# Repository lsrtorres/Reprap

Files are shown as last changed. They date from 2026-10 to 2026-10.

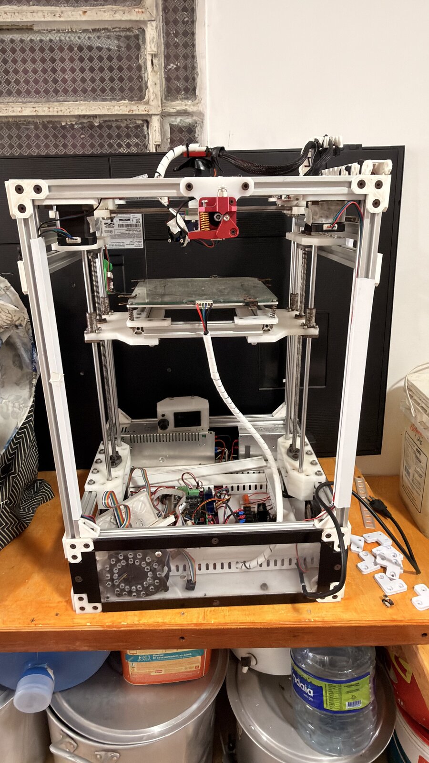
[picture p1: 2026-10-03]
Fotos/jpg/IMG_0317.jpg

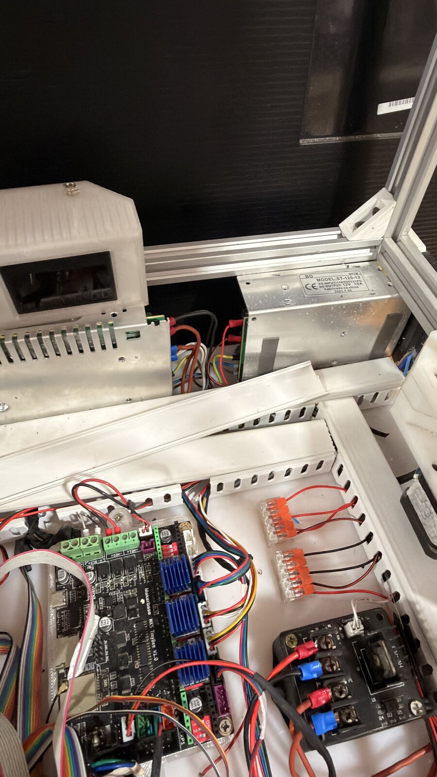
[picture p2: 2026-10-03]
Fotos/jpg/IMG_0322.jpg

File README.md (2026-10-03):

# Projeto RepRap — Redesenho para 200×200×200

Projeto colaborativo de atualização/redesenho de uma impressora 3D RepRap existente (estilo Ultimaker, gantry de eixos cruzados) para um volume de impressão de **200×200×200 mm**, reaproveitando **todos os componentes atuais** (motores, fusos, guias, eletrônica, fontes, mesa, etc.).

## Objetivos

1. Volume de impressão final: **200 × 200 × 200 mm**
2. Reaproveitar todos os componentes existentes (ver [inventário](Docs/01-inventario-componentes.md))
3. Modelagem completa em **Fusion 360**, com exportação de STEP/F3D versionados neste repositório
4. Estrutura em perfil de alumínio (temos perfis de 380 mm e 630 mm; podemos comprar mais)

## Estrutura do repositório

| Pasta | Conteúdo |
|---|---|
| `Docs/` | Documentação: inventário, análise da máquina atual, requisitos e registro de decisões |
| `Fotos/` | Fotos da impressora atual (originais `.heic` + convertidas em `Fotos/jpg/`) |
| `CAD/` | Modelos do Fusion 360 exportados (`.f3d`, `.step`) e STEPs de componentes de terceiros |
| `Firmware/` | Configuração de firmware (Marlin para MKS TinyBee) quando chegarmos nessa fase |
| `Memoria/` | Memória persistente do assistente (Claude Code) — versionada junto com o projeto |

### Memória do assistente (`Memoria/`)

O Claude Code guarda a memória por projeto em `~\.claude\projects\c--Reprap\memory\`. Para que ela seja versionada (requisito do projeto), esse diretório é uma **junction do NTFS** apontando para `Memoria/` dentro do repositório. Em uma máquina nova, após clonar o repo, recriar a junction (PowerShell):

```powershell
Remove-Item "$env:USERPROFILE\.claude\projects\c--Reprap\memory" -Recurse -Force -ErrorAction SilentlyContinue
New-Item -ItemType Junction -Path "$env:USERPROFILE\.claude\projects\c--Reprap\memory" -Target "C:\Reprap\Memoria"
```

(ajustar o sufixo `c--Reprap` conforme o caminho local do clone.)

## Documentos principais

- [01 — Inventário de componentes](Docs/01-inventario-componentes.md)
- [02 — Análise da máquina atual](Docs/02-analise-maquina-atual.md)
- [03 — Requisitos e registro de decisões](Docs/03-requisitos-e-decisoes.md)
- [04 — Conceito do novo gantry (CoreXY)](Docs/04-conceito-novo-gantry.md)
- [05 — Lista de compras](Docs/05-lista-de-compras.md)
- [06 — Conceito do eixo Z (estilo Voron Trident)](Docs/06-conceito-z-voron.md)
- [07 — Esqueleto dimensional do gantry](Docs/07-esqueleto-gantry.md)
- [08 — Esqueleto dimensional da máquina completa](Docs/08-esqueleto-maquina.md)
- [09 — Montagem peça a peça no Fusion 360 (juntas + simulação)](Docs/09-montagem-fusion.md)
- [10 — Roteiro Fusion, Fase 1: o frame](Docs/10-roteiro-fusion-fase1-frame.md)

## Fluxo de trabalho de CAD

O Fusion 360 salva os projetos na nuvem da Autodesk. Para manter o repositório como fonte de verdade colaborativa:

1. Modelar no Fusion 360 normalmente;
2. Ao fechar uma etapa, exportar `.f3d` (com histórico paramétrico) e `.step` (neutro) para `CAD/`;
3. Commitar com mensagem descrevendo a mudança;
4. STEPs de componentes comprados (motores NEMA17, perfis, trilhos MGN, etc.) ficam em `CAD/componentes/`.

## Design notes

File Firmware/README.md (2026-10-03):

# Firmware — Klipper

Decisão de 2026-10-03 ([registro](../Docs/03-requisitos-e-decisoes.md)): a impressora roda **Klipper** na **MKS SKIPR** — host (SoC quad-core, imagem da MKS com Klipper/Moonraker/Fluidd-Mainsail) e MCU (STM32) na mesma placa. O Leandro já opera outra RepRap com Klipper.

Esta pasta vai receber o **`printer.cfg`** (versionado — toda mudança de configuração entra por commit) e macros.

## Sementes do printer.cfg (valores já decididos)

| Parâmetro | Valor | Origem |
|---|---|---|
| `kinematics` | `corexy` | [Docs/04](../Docs/04-conceito-novo-gantry.md) |
| `rotation_distance` X/Y | **40** (GT2 2 mm × polia 20T) | polias existentes |
| `rotation_distance` Z (×3) | **8** (TR8×8) | [Docs/06](../Docs/06-conceito-z-voron.md) |
| Steppers | `stepper_x`, `stepper_y`, `stepper_z`, `stepper_z1`, `stepper_z2`, `extruder` | SKIPR: 6 de 7 slots |
| `[probe]`/`[bltouch]` | BLTouch | lista de compras item 11 |
| `[z_tilt]` | 3 pontos (2 frontais + 1 central traseiro) — coordenadas sairão do CAD | [Docs/06](../Docs/06-conceito-z-voron.md) |
| `[bed_mesh]` | janela 200×200 centrada em (0, −35) do sistema do anel — mapear p/ coords da mesa | [Docs/07](../Docs/07-esqueleto-gantry.md) |
| Drivers | 6× **TMC2209 em UART** (`[tmc2209 stepper_*]`, `run_current` a definir pela etiqueta dos motores); sensorless homing = opção futura | inventário (5 existentes + 1 a comprar) |
| Mesa | MK3 12 V via MOSFET externo, termistor 100k | inventário |
| Hotend | V6 Volcano 12 V, 40 W | lista de compras item 16 |
| Extrusora | direct-drive vermelha atual — `rotation_distance` a calibrar | inventário (modelo pendente) |

## Pendências

1. ~~Escolha do host~~ ✅ embutido na SKIPR
2. Gravar a imagem oficial da MKS p/ SKIPR no microSD; definir rede (Ethernet ou dongle WiFi USB)
3. Modelo dos drivers atuais (corrente de referência / jumpers de microstep na SKIPR)
4. Posições exatas dos 3 fusos para o `[z_tilt]` (sai do CAD do Z)
5. ADXL345 (opcional) para input shaper

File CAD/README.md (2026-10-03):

# CAD

Modelos do projeto.

- Raiz: montagens e peças (`.f3d` com histórico paramétrico do Fusion 360 + `.step` neutro)
- `componentes/`: STEPs de componentes comprados/padrão (gerados por script — envelopes dimensionais)
- `scripts/`: scripts Python/CadQuery que **geram** o esqueleto e os componentes — ver [Docs/07](../Docs/07-esqueleto-gantry.md) para o sistema de coordenadas e instruções de regeneração

Convenção de nomes: `NN-nome-da-peca_vX.step` (ex.: `10-esqueleto-gantry_v1.step`). O `.f3d` correspondente acompanha a mesma numeração.

Regra de ouro: dimensões "mestras" vivem em [`scripts/parametros.py`](scripts/parametros.py) e no registro de decisões — se mudar uma dimensão de conceito, mudar lá e regenerar.

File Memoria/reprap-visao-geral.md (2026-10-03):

---
name: reprap-visao-geral
description: "Projeto RepRap 200x200x200 - repo, convencoes e onde esta a memoria real do projeto"
metadata:
  node_type: memory
  type: project
  originSessionId: 7e4093a0-5cda-47a9-a74d-79533ce589c3
  modified: 2026-10-03T14:39:08.445Z
---

Redesenho de impressora RepRap (estilo Ultimaker: XY cruzado no topo, mesa desce no Z) para volume 200×200×200 mm, reaproveitando todos os componentes. Repo local `C:\Reprap` → `https://github.com/lsrtorres/Reprap.git` (branch main, identidade git local: lsrtorres / lsrtorred@gmail.com).

**A memória real do projeto vive no repositório** (requisito do Leandro: tudo commitável): `Docs/01-inventario-componentes.md` (inventário + medições pendentes), `Docs/02-analise-maquina-atual.md`, `Docs/03-requisitos-e-decisoes.md` (registro de decisões), `Docs/04-conceito-novo-gantry.md`. Decidido em 2026-10-03: **CoreXY aprovado** (anel 440 mm; guias Y = MGN9×300 nos laterais; viga X = perfil 20×20 + MGN9 na face frontal; juntas XY estilo Voron com polias encapsuladas; correias ancoram por ranhuras atrás do toolhead). **Z estilo Voron Trident**: 3 guias MGN (2 frontais + 1 central traseira); acionamento proposto = 2 TR8 frontais + seguidor (TinyBee só tem 5 slots de driver — detalhes em `Docs/06`). Z confirmado: **Trident completo** — nova placa **MKS SKIPR** (Klipper host embutido + MCU STM32, 7 slots; TinyBee vira reserva; exceção ao reuso aprovada), 3× fuso TR8×8×400 + castanhas bronze com 3 motores independentes, mancais KP08/KFL08, motores embaixo, BLTouch; +1 NEMA17 e +1 driver a comprar; hotend novo V6 Volcano 12 V (extrusora vermelha continua). **Firmware: Klipper** (Leandro já tem outra RepRap com Klipper; `z_tilt` 3 pontos; display MKS TFT vira reserva; UI Mainsail/Fluidd). Sementes do printer.cfg em `Firmware/README.md`. Esqueleto CAD paramétrico em `CAD/scripts/` (CadQuery; venv em `C:\Reprap\.venv`, Python 3.12): `esqueleto_gantry.py` → `CAD/10-...step` e `esqueleto_maquina.py` → `CAD/11-esqueleto-maquina_v1.step` (máquina completa com Z Trident; verificações automáticas de curso XY/Z; drivers = TMC2209). Coordenadas/stack-up em `Docs/07` e `Docs/08`. Perfis (correção final): comprar 3×440 + 11×400; colunas = 4×630 do estoque inteiras (só existem 4) + coluna Z traseira é um 440 comprado; único corte do projeto: viga X 400→340. Fluxo Fusion (Docs/09): upload de cada STEP no Data Panel → componente X-ref inserido um a um → juntas rígidas + sliders + motion link (fuso 8mm/volta) p/ simular movimentos; Leandro traz STEPs de fabricante (MGN9C, KP08, castanha T8); mudou conceito → editar `parametros.py`, regenerar, re-upload como nova versão do mesmo item. Barras Ø8 eram guias do Z atual; serão aposentadas. Sempre ler esses docs no início da sessão e registrar decisões novas lá, com commit.

**Status em 2026-10-03**: Leandro montando a **Fase 1 (frame, 17 perfis)** no Fusion seguindo `Docs/10` (método: gabarito 11-esqueleto aterrado + Move "Point to Point" por vértice; Fusion não tem tipo "montagem" — é Design comum com componentes X-ref). Ele já baixou o carrinho HIWIN **MGN9H** (`CAD/componentes/mgn9h-carrinho-hiwin.step`) — ⚠️ confirmar se os carrinhos físicos são MGN9**C** (38,5 mm, assumido no esqueleto) ou MGN9**H** (~48,9 mm — cursos ainda fecham, mas `parametros.py` precisaria de MGN9_BLOCO_L atualizado e regenerar). Próximo: Fase 2 = trilhos + gantry + sliders.

CAD: Fusion 360 (nuvem Autodesk); exportar .f3d + .step para `CAD/`. Fotos HEIC convertidas para JPG em `Fotos/jpg/` (ImageMagick instalado via winget; HEIC não é legível diretamente). [[leandro-perfil]]

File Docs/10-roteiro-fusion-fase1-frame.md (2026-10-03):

# 10 — Roteiro Fusion, Fase 1: o frame (16 perfis)

Companheiro do [09](09-montagem-fusion.md). Método: usar o **esqueleto como gabarito** e encaixar cada componente nele com *Point to Point* — zero digitação de coordenada, precisão total.

## Fase 0 — Projeto e uploads

1. Data Panel → **New Project**: `Reprap`; dentro dele, pasta `componentes`
2. Upload para `componentes/`: `perfil-2020-630.step`, `perfil-2020-440.step`, `perfil-2020-400.step` (os 3 bastam p/ a Fase 1)
3. Upload na raiz do projeto: `11-esqueleto-maquina_v1.step` (o gabarito)
4. Aguardar o processamento de cada upload terminar (ícone pára de girar)

## Fase 1 — Montagem do frame

### Preparação

1. **New Design**, salvar como `montagem-reprap` (unidades: mm — padrão)
2. Inserir o gabarito: botão direito em `11-esqueleto-maquina_v1` → *Insert into Current Design* → **OK sem mover nada**
3. Botão direito no gabarito na árvore → **Ground**. Renomear para `GABARITO`

### Encaixe de cada perfil (receita de 2 passos)

Para cada linha da tabela abaixo:

1. *Insert into Current Design* no perfil indicado → OK (ele cai na origem)
2. **Se a tabela pedir rotação**: `M` (Move/Copy) → *Components* → girar **90° no eixo indicado** (o pivô não importa — o passo 3 corrige a posição)
3. `M` → *Move Type: **Point to Point*** → clicar num **vértice de canto** do perfil inserido → clicar no **vértice correspondente** do membro homônimo do GABARITO. Pronto: encaixado com exatidão
4. Renomear a instância na árvore com o nome da tabela

| Ordem | Componente | Instância (nome) | Rotação | Onde encaixa (membro do gabarito) |
|---|---|---|---|---|
| 1–4 | `perfil-2020-630` | `coluna-0..3` | nenhuma (já é vertical) | 4 colunas dos cantos |
| 5–6 | `perfil-2020-400` | `base-lateral-esq/dir` | **90° em X** | anel da base, laterais |
| 7–8 | `perfil-2020-400` | `base-frente/tras` | **90° em Y** | anel da base, frente e trás |
| 9–10 | `perfil-2020-400` | `deck-lateral-esq/dir` | **90° em X** | deck, laterais |
| 11–12 | `perfil-2020-400` | `deck-frente/tras` | **90° em Y** | deck, frente e trás |
| 13–14 | `perfil-2020-440` | `perfil-esq/dir` | **90° em X** | anel superior, laterais (sobre as colunas) |
| 15–16 | `perfil-2020-400` | `perfil-frente/tras` | **90° em Y** | anel superior, frente e trás |
| 17 | `perfil-2020-440` | `coluna-z-tras` | nenhuma | coluna central traseira (do deck ao anel) |

> Regra de bolso da rotação: membro que corre na direção **Y** (laterais) → girar em **X**; membro que corre em **X** (frente/trás) → girar em **Y**. O perfil é simétrico, o sinal do giro não importa.

### Espans de referência (conferência, se quiser medir)

| Grupo | Ocupação |
|---|---|
| Colunas | (x, y) = (±210 ± 10), z −650 … −20 |
| Anel base | z −650 … −630 |
| Deck | z −480 … −460 |
| Anel superior | z −20 … 0 (laterais de 440 cobrem y −220 … +220) |
| Coluna Z traseira | (0 ± 10, 210 ± 10), z −460 … −20 |

### Fechamento da fase

1. Selecionar os 17 componentes (não o GABARITO) → botão direito → **Rigid Group** → nomear `frame`
2. **Ground** num deles (o grupo todo trava)
3. Ocultar o `GABARITO` (olhinho na árvore) — **não apagar**: ele guia as fases 2 (trilhos + gantry) e 3 (Z + mesa)
4. Conferir com *Inspect → Measure*: externo 440 × 440, altura total 650 do piso ao topo do anel

### Resultado esperado

Frame completo: 4 colunas + 3 anéis (base, deck, superior) + coluna Z traseira — idêntico ao gabarito, mas com cada perfil sendo um componente X-ref independente, pronto para receber trilhos e juntas na Fase 2.

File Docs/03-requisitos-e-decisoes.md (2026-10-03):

# 03 — Requisitos e registro de decisões

Este documento é a memória viva do projeto. Toda decisão relevante entra na tabela de decisões com data e justificativa. Alterações via commit — o histórico do git é o registro oficial.

## Requisitos

| # | Requisito | Tipo |
|---|---|---|
| R1 | Volume de impressão de 200 × 200 × 200 mm | Obrigatório |
| R2 | Reaproveitar todos os componentes atuais (motores, fusos, guias, eletrônica, fontes, mesa, display, extrusora/hotend) | Obrigatório |
| R3 | Estrutura em perfil de alumínio; estoque atual: 380 mm e 630 mm; compra de perfis adicionais é permitida | Obrigatório |
| R4 | Fixação dos perfis com cantoneiras externas, parafuso M5 + porca T (padrão atual) — pode evoluir se justificado | Desejável |
| R5 | Modelagem completa em Fusion 360, com F3D/STEP versionados no repositório | Obrigatório |
| R6 | Projeto colaborativo: tudo (docs, CAD, decisões, memória) versionado no git | Obrigatório |
| R7 | Peças impressas em 3D fabricáveis na própria máquina atual (bootstrap) | Desejável |
| R8 | Novo roteamento de correias: chegada limpa e direta das correias ao toolhead e ao gantry XY (insatisfação com o esquema atual estilo Ultimaker) | Obrigatório |

## Registro de decisões

| Data | Decisão | Justificativa | Status |
|---|---|---|---|
| 2026-10-03 | Repositório git como fonte de verdade do projeto (docs + CAD exportado + fotos) | Projeto colaborativo; Fusion 360 fica na nuvem Autodesk, mas exportações F3D/STEP são versionadas | ✅ Ativa |
| 2026-10-03 | Fotos originais `.heic` mantidas + conversões `.jpg` (1600 px) para visualização no GitHub | GitHub não renderiza HEIC; JPGs facilitam a colaboração | ✅ Ativa |
| 2026-10-03 | Perfis adicionais podem ser comprados (20×20, mesmo padrão) | Necessário: quadro atual (380 mm) só entrega ~180 mm de curso | ✅ Ativa |
| 2026-10-03 | Fusos Z: **manter os TR8 atuais** | Confirmado que já são trapezoidais TR8 — sem motivo para troca | ✅ Ativa |
| 2026-10-03 | **Cinemática do novo gantry: CoreXY** — correias ancoram direto no carro do toolhead, motores fixos no quadro — ver [04-conceito-novo-gantry.md](04-conceito-novo-gantry.md) | Atende R8; elimina eixos rotativos e correias perimetrais do estilo Ultimaker; reusa os 2 motores XY e polias; Marlin `COREXY` nativo na TinyBee. **Aprovado pelo Leandro** | ✅ Ativa |
| 2026-10-03 | **Viga X = perfil 20×20 + trilho MGN montado nele**; toolhead corre no MGN | Pedido do Leandro (robustez); perfil dá rigidez torcional que barras não dão | ✅ Ativa |
| 2026-10-03 | Trilho MGN na **face frontal** da viga X (não no topo), estilo Voron | Sugestão do Leandro: placa do toolhead plana, CG do cabeçote perto do trilho (menos momento), topo livre p/ esteira — detalhes em [04](04-conceito-novo-gantry.md) | ✅ Ativa |
| 2026-10-03 | ~~Guias Y = 2 barras Ø8×400 com LM8UU~~ | Substituída no mesmo dia ao confirmar que existem 4 trilhos MGN9 | ♻️ Substituída |
| 2026-10-03 | **Guias Y = 2× trilho MGN9 300 mm** parafusados nos perfis laterais; viga X usa o 3º trilho; 4º fica de reserva | **Mantém a solução da máquina atual** (o Y já corre em 1 MGN9 de cada lado; barras lisas só existem no Z); carros Y viram placas simples e dispensa LM8UU | ✅ Ativa |
| 2026-10-03 | **Juntas XY estilo Voron**: polias desviadoras **encapsuladas** dentro das peças que unem a viga X aos carrinhos Y (não expostas no topo) | Pedido do Leandro; protege as polias, alinha os dois planos de correia por construção e enrijece a junta | ✅ Ativa |
| 2026-10-03 | **Ancoragem das correias por ranhuras** na traseira do carro do toolhead (dente da GT2 morde a ranhura impressa), uma por plano de correia | Pedido do Leandro; elimina a peça única "de dois andares", facilita troca de correia e tensionamento | ✅ Ativa |
| 2026-10-03 | **Z estilo Voron Trident nas guias**: 3 guias MGN verticais (2 colunas frontais + 1 central traseira), mesa em 3 pontos; torres atuais com barras Ø8 aposentadas | Pedido do Leandro; conceito detalhado em [06-conceito-z-voron.md](06-conceito-z-voron.md) | ✅ Ativa |
| 2026-10-03 | ~~Acionamento do Z (Opção A): 2 fusos frontais + seguidor passivo~~ | Substituída no mesmo dia: Leandro decidiu comprar placa com mais slots para viabilizar o Trident completo | ♻️ Substituída |
| 2026-10-03 | ~~Nova placa: MKS Monster8 V2~~ | Substituída no mesmo dia: com o firmware fechado em Klipper, o Leandro escolheu a placa com host embutido | ♻️ Substituída |
| 2026-10-03 | **Nova placa: MKS SKIPR** (SoC quad-core com Klipper host embutido + MCU STM32, **7 slots de driver**, entrada 12–24 V); TinyBee vira reserva. **Exceção aprovada ao R2** (reuso total) | Decisão do Leandro; elimina host externo (sem Pi, sem buck 5 V), reusa os 5 drivers atuais; 6 slots usados (X, Y, 3×Z, E) + 1 folga; rede via Ethernet ou dongle WiFi USB | ✅ Ativa |
| 2026-10-03 | **Acionamento do Z: Trident completo — 3 fusos TR8×8×400 com 3 motores independentes** (`G34`/`Z_STEPPER_AUTO_ALIGN` de 3 pontos com BLTouch) | Com a Monster8 há slots de sobra; auto-tram verdadeiro (rolagem + inclinação); requer +1 NEMA17, +1 fuso/castanha/mancal/acoplador e +1 driver | ✅ Ativa |
| 2026-10-03 | **Fusos Z novos: 3× TR8×8 (passo 8) × 400 mm + castanhas de bronze**; apoio em **mancal KP08/KFL08** na base, motor embaixo; TR8 atuais viram reserva | Especificação do Leandro (qtde atualizada de 2→3 com o Trident completo); passo 8 dá Z rápido (400 steps/mm @ 16 µsteps) | ✅ Ativa |
| 2026-10-03 | **Firmware: Klipper** (TinyBee/ESP32 nem roda Klipper). Nivelamento: `Z_TILT_ADJUST` 3 pontos + `BED_MESH_CALIBRATE` com BLTouch. Display MKS TFT atual → reserva (UI = Mainsail/Fluidd no navegador) | Decisão do Leandro — já opera outra RepRap com Klipper; CoreXY + input shaper é o ponto forte do Klipper | ✅ Ativa |
| 2026-10-03 | **Host do Klipper: embutido na MKS SKIPR** | Decisão do Leandro — resolve a decisão aberta de host junto com a placa | ✅ Ativa |
| 2026-10-03 | **Sonda BLTouch** no toolhead | Especificação do Leandro; vidro exige sonda de pino; TinyBee tem porta 3D-Touch; habilita `G34` + `G29` | ✅ Ativa |
| 2026-10-03 | **Hotend novo: V6 com bloco Volcano, 12 V** (cartucho 40 W + termistor) | Especificação do Leandro; substitui o hotend atual; extrusora vermelha direct-drive continua | ✅ Ativa |
| 2026-10-03 | Divisão de energia: fonte **360 W → mesa + hotend + motores/placa**; fonte **120 W → ventoinhas/iluminação/aux** (detalhar na fase de eletrônica) | Mesa MK3 12 V puxa ~10–11 A sozinha; 30 A comportam o sistema todo com margem | ✅ Ativa |
| 2026-10-03 | Anel XY com perfis 20×20 de **440 mm** (vão interno 400 mm) — **aprovado para compra** | Comporta 200 mm de curso com folga nos dois eixos; dimensional em [04](04-conceito-novo-gantry.md); lista de compras em [05](05-lista-de-compras.md). **OK do Leandro** | ✅ Ativa |

## Próximos passos

1. **[Leandro]** Fazer o pedido da [lista de compras](05-lista-de-compras.md) (perfis: **3× 440 + 11× 400** — estoque de 630 confirmado em 4, usados inteiros)
2. **[Leandro]** Montagem no Fusion pelo fluxo do [09](09-montagem-fusion.md): upload dos STEPs de `CAD/componentes/` + STEPs de fabricante (MGN9C, KP08, castanha T8), inserção um a um, juntas rígidas/sliders e simulação de movimentos
3. Modelagem das peças impressas no Fusion 360, na ordem do [08](08-esqueleto-maquina.md): juntas XY, carro do toolhead (Volcano+BLTouch), blocos de motor, braços da mesa, suportes do deck/baia
4. **[Leandro]** Pendências leves do inventário: etiqueta dos motores, modelo da extrusora, contagem dos perfis 380

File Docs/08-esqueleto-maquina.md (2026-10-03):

# 08 — Esqueleto dimensional da máquina completa

Gerado por [`CAD/scripts/esqueleto_maquina.py`](../CAD/scripts/esqueleto_maquina.py), que importa o gantry do script anterior e adiciona o frame vertical e o Z Trident. Saída: **`CAD/11-esqueleto-maquina_v1.step`** (abre direto no Fusion 360). Mesmo sistema de coordenadas do [Docs/07](07-esqueleto-gantry.md) (origem no centro do anel superior, z=0 no topo do anel).

## Arquitetura vertical (de cima para baixo)

| z (mm) | Elemento |
|---|---|
| −20 … 0 | **Anel superior** (2× 440 laterais sobre as colunas + 2× 400 frente/trás) + gantry CoreXY |
| −55 | Ponta do bico (V6 Volcano, estimado) = topo do vidro com a mesa em **home** |
| −50 … −350 | **Trilhos Z** MGN9×300: 2 nas colunas frontais (face interna) + 1 na coluna central traseira |
| −67 … −267 | Topo dos braços da mesa ao longo do curso de **200 mm** |
| −55 … −455 | **Fusos TR8×8 × 400** (3×): sobra +12 mm acima da castanha em home, +168 mm na base |
| −460 … −480 | **Deck** (4× perfil 400 entre colunas): mancais KP08/KFL08 em cima, motores Z pendurados embaixo |
| −480 … −630 | **Baia da eletrônica**: 150 mm internos p/ SKIPR, 2 fontes, MOSFET, WAGOs |
| −630 … −650 | **Anel da base** (4× perfil 400 entre colunas), no chão |
| −650 | Piso |

- **Colunas**: 4× perfil **630 inteiro** nos cantos (do piso até sob o anel superior — estoque confirmado: exatamente 4) + 1 coluna central traseira de **440** (comprada — mesma medida das laterais do anel), do deck ao anel — carrega o 3º trilho Z
- **Mesa**: rígida em 3 pontos (**sem molas** — `z_tilt` + `bed_mesh` substituem o nivelamento manual); vidro 3 + MK3 3 + espaçador 6 + braço 8
- Posições dos fusos: frontais (±180, −195), traseiro (0, +195) — coordenadas que depois alimentam o `[z_tilt]` do Klipper

## Verificações automáticas (o script falha se alguma quebrar)

| Checagem | Resultado |
|---|---|
| Curso XY do bico ≥ 200 | 261,5 mm ✓ (folga +30,8/lado) |
| Fuso cobre a castanha em todo o curso Z | ✓ (+12 topo / +168 base) |
| Carrinho Z dentro do trilho em todo o curso | ✓ (−71…−271 dentro de −69,2…−330,8) |
| Baia ≥ 90 mm p/ fontes | ✓ 150 mm |
| Mesa não colide com colunas | ✓ |

## Lista de corte consolidada (perfis 20×20)

| Origem | Peças |
|---|---|
| **Comprar** | 3× **440** + 11× **400** |
| **Estoque (630)** | 4× inteiros (colunas dos cantos) — sem corte |
| **Estoque (380)** | livres p/ travessas da baia (suportes de fonte/SKIPR) e reforços |

> Único corte de perfil do projeto: a viga X (400 → 340).

## Fluxo com o Fusion 360

O STEP é o formato neutro que o Fusion abre nativamente — **todo o trabalho de modelagem continua no Fusion 360**; os scripts só produzem a referência dimensional:

1. *File → Open* (ou *Insert → Insert CAD*) no `11-esqueleto-maquina_v1.step` — a árvore vem com os componentes **nomeados** (perfis, trilhos, fusos, motores…)
2. `Ground` nos perfis; modelar cada peça impressa como componente novo **referenciando as faces do esqueleto**
3. O STEP não traz histórico paramétrico nem juntas (é geometria estática) — se uma dimensão de conceito mudar, eu altero [`parametros.py`](../CAD/scripts/parametros.py), regenero, e re-importamos a nova versão
4. Peças modeladas voltam ao repositório como F3D + STEP em `CAD/`

## Próximas peças a modelar (Fusion 360)

1. Juntas XY com polias encapsuladas (2×, espelhadas)
2. Carro do toolhead (ranhuras GT2 + V6 Volcano + BLTouch + extrusora vermelha)
3. Blocos dos motores A/B e das polias dianteiras
4. Braços da mesa (3×) com alojamento de castanha e interface MGN9
5. Suportes de mancal/motor Z no deck; suportes da SKIPR/fontes na baia
6. Cantoneiras/uniões dos perfis (padrão M5 + porca T)

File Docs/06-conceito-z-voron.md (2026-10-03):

# 06 — Conceito do eixo Z (estilo Voron Trident)

**Decisão do Leandro (2026-10-03):** o Z passa a ser ancorado em **guias MGN verticais — duas na frente e uma no centro traseiro** —, com a mesa suportada em 3 pontos, no estilo Voron Trident. As torres atuais (fuso + 2 barras Ø8 cada) são aposentadas; as barras Ø8×~400 viram reserva.

## Arquitetura

```
   vista de cima (anel da base)          vista frontal
   ┌─────────[MGN]─────────┐          ║ col.    col. ║
   │          trás          │          ║ MGN     MGN ║
   │                        │          ║ │         │ ║
   │      mesa 220×220      │          ║ ├─ mesa ──┤ ║
   │     (3 braços p/       │          ║ │  braços │ ║
   │      os carrinhos)     │          ║ TR8     TR8 ║
 [MGN]                   [MGN]         ║ (fusos)     ║
   └──frente────────────────┘          ╚═════════════╝
```

- **Guias**: 3× trilho MGN9×300 vertical — 2 parafusados nas faces internas das colunas frontais + 1 numa coluna central traseira (perfil 20×20 adicionado ao quadro). Curso útil ≈ 300 − carrinho (39) − margens ≈ **~250 mm** → atende os 200 mm com folga
- **Mesa**: MK3 220×220 + vidro sobre 3 braços (frente-esq., frente-dir., centro-trás) parafusados nos carrinhos — suporte em 3 pontos, o único que não empena a mesa por definição
- **Trilhos**: temos 1 MGN9×300 de reserva; **comprar 2** (já estão na [lista de compras](05-lista-de-compras.md))
- **Colunas**: perfis de 630 mm existentes; a coluna central traseira pode sair do estoque de 380 mm se a altura da zona Z permitir (fechar no CAD)

## Acionamento — Trident completo com MKS SKIPR

A TinyBee tem só 5 slots de driver (X, Y, Z, E0, E1) — com CoreXY + extrusora sobrariam 2 para o Z. **Decisão (2026-10-03): comprar uma MKS SKIPR** (SoC quad-core com **Klipper host embutido** + MCU STM32, 7 slots de driver, entrada 12–24 V) e fazer o **Trident completo**:

- **3 fusos TR8 × 400 mm, passo 8 mm** (TR8×8, 4 entradas) + **castanhas de bronze** — frontal-esq., frontal-dir. e central traseiro; os TR8 atuais viram reserva
- **3 motores NEMA17 independentes** (2 existentes + **1 a comprar**), cada um no seu slot → **`Z_TILT_ADJUST` do Klipper em 3 pontos** com a BLTouch: auto-tram verdadeiro de rolagem **e** inclinação (firmware decidido: **Klipper**)
- **Mancais KP08 ou KFL08 (Ø8)** na base, um por fuso — motor embaixo, acoplador 5×8, mancal logo acima, ponta superior do fuso livre
- **Sonda: BLTouch** — `Z_TILT_ADJUST` + `BED_MESH_CALIBRATE` sobre o vidro
- Slots da SKIPR: X, Y, E0 + 3× Z = 6 usados, 1 de folga (no Klipper cada stepper é declarado livremente no `printer.cfg`)
- **Drivers**: reaproveitam-se os 5 atuais + 1 igual a comprar (identificar o modelo — pendência do inventário); Klipper aceita qualquer driver step/dir; upgrade opcional futuro: jogo de TMC2209 (UART)
- **TinyBee**: vira reserva (exceção ao requisito R2 aprovada pelo Leandro) — ESP32 não roda Klipper de qualquer forma
- **Host Klipper**: **embutido na SKIPR** (sem Pi externo); rede via Ethernet RJ45 ou dongle WiFi USB; interface Mainsail/Fluidd no navegador

> `rotation_distance` no Klipper: Z com TR8×8 = **8**; XY com GT2 + polia 20T = **40**.

Alternativas descartadas: manter TinyBee com 2 fusos + seguidor passivo (pitch não ajustável por software); 3 fusos sincronizados por correia (tram mecânico).

## O que é liberado dos componentes atuais

| Componente | Destino |
|---|---|
| 4× barra Ø8×~400 (torres) | Reserva |
| 8× LM8UU (ou similares das torres) | Reserva |
| 2× fuso TR8 atual | Reserva (substituídos por 3× TR8×8 400 mm novos) |
| Hotend atual (envolto em fita) | Reserva (substituído por V6 Volcano 12 V) |
| **MKS TinyBee V1.0** | Reserva (substituída pela Monster8 V2 — exceção ao R2 aprovada) |
| Perfis das torres | Voltam ao estoque (380/630) |

## Pendências desta fase

1. ~~Confirmar acionamento~~ ✅ Opção A com TR8×8 400 + KP08/KFL08 + BLTouch
2. CAD: braços da mesa, suportes de fuso/motor, posição exata da coluna traseira, altura da zona Z (dimensionar com o curso de 200 + espessuras da mesa)

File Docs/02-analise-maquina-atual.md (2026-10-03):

# 02 — Análise da máquina atual

Baseada nas fotos de 2026-10-03 (`Fotos/jpg/IMG_0317...0328`). A máquina está montada e **funcional**.

## Arquitetura geral

Impressora de pórtico superior **estilo Ultimaker**:

- **XY no topo**: cabeçote na interseção de eixos cruzados, acionado por correias GT2. O gantry XY é **todo guiado por trilhos MGN9** (Y: um de cada lado; X: no eixo transversal) — barras lisas só existem no Z. Motores X/Y fixados por baixo dos perfis superiores, nos cantos traseiros (IMG_0328/0320/0326).
- **Z**: a mesa desce durante a impressão. Duas torres laterais, cada uma com 1 fuso TR8 central + 2 barras lisas Ø8×~400; os fusos são acionados por motores no **topo** das torres (IMG_0317). Porcas de bronze nas plataformas (IMG_0325).
- **Cabeçote**: extrusora direct-drive (corpo vermelho) sobre o carro central, hotend para baixo (IMG_0317/0326). Cabos levados por esteira porta-cabos impressa em branco.
- **Mesa**: vidro com clipes sobre plataforma impressa com 4 molas de nivelamento (IMG_0317/0325).
- **Base**: caixa inferior em perfis + chapas perfuradas brancas abrigando as 2 fontes, a MKS TinyBee, o MOSFET da mesa e a distribuição WAGO; 2 ventoinhas no painel frontal (IMG_0321/0322/0323).
- **Estrutura**: perfis de alumínio unidos por placas/cantoneiras impressas externas com M5 + porca T. Display no meio da coluna frontal.

## Pontos fortes (a preservar)

1. **Arquitetura estável**: cabeçote leve no XY, massa da mesa só no Z — bom para velocidade.
2. **Eletrônica moderna**: MKS TinyBee (ESP32) roda Marlin 2.x com WiFi — ótima base.
3. **Caixa de eletrônica separada** na base, com ventilação própria.
4. **Distribuição elétrica organizada** com WAGO e MOSFET externo para a mesa.
5. Estrutura em perfil de alumínio — fácil de redimensionar e expandir.

## Fragilidades observadas (candidatas a melhoria no redesenho)

1. **Peças impressas estruturais grandes** (plataformas do Z, blocos do gantry) — algumas aparentam desgaste/folga; redesenhar com reforço ou substituir por conjuntos mais rígidos.
2. **Fusos Z aparentam ser barra roscada comum** com sinais de oxidação/sujeira (IMG_0323/0324) — se confirmado, considerar limpeza/lubrificação ou upgrade para TR8 (mantendo se o objetivo for custo zero).
3. **Acionamento Z por cima** com fuso longo em balanço embaixo — alinhamento crítico; avaliar mancal inferior.
4. **Cabeamento** parcialmente solto na caixa da base — refazer com canaletas já existentes e identificação.
5. **Hotend envolto em fita** (IMG_0326) — avaliar estado térmico real, silicone sock ou reisolamento.
6. **Tensionamento de correia por esticador simples** — prever tensionadores ajustáveis no redesenho.
7. **Fonte 1 de 120 W (12 V 10 A)**: se a mesa aquecida for 12 V ~10–12 A, a soma com hotend+motores exige as duas fontes bem separadas por função — documentar a divisão atual antes de mexer.

## Implicações para o redesenho 200×200×200

- **O quadro atual não entrega 200 mm**: perfis de 380 mm (20×20) dão vão interno de ~340 mm, e o curso real medido é **~180 mm** — os blocos deslizantes e o carro central do gantry Ultimaker consomem ~160 mm de vão. Para 200 mm de curso será preciso **comprar perfis maiores para o anel XY** e/ou mudar para uma cinemática que consuma menos vão (CoreXY).
- O Leandro quer **mudar o roteamento das correias** (como chegam ao toolhead e ao próprio gantry) — ver [04-conceito-novo-gantry.md](04-conceito-novo-gantry.md).
- Curso Z de 200 mm é tranquilo com as torres atuais (perfis de 630 mm dão espaço de sobra para fuso + mesa + base).
- Mesa MK3 220×220 comporta os 200×200 úteis com margem de 10 mm por lado.
- A caixa de eletrônica na base pode ser mantida conceitualmente igual, só redimensionada.

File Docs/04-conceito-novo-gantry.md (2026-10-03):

# 04 — Conceito do novo gantry XY (roteamento de correias)

**Motivação (R8):** no gantry atual, estilo Ultimaker, as correias não chegam diretamente ao toolhead: os motores acionam eixos rotativos, que acionam 4 correias perimetrais, que movem blocos deslizantes, que movem as barras cruzadas, que finalmente movem o toolhead. São muitos elementos em série (folgas se somam), tensionamento difícil e manutenção chata. O Leandro pediu explicitamente para mudar como as correias chegam ao toolhead e ao gantry.

## Opções avaliadas

### Opção A — CoreXY (recomendada ✅)

Duas correias contínuas em dois planos empilhados (~10 mm de distância vertical). **As duas correias ancoram diretamente no carro do toolhead** — sem eixos intermediários, sem blocos acionados por correia.

```
  motor A ◼──────────────◼ motor B      (traseira)
         │╲              ╱│
         │ ╲            ╱ │
  guia Y │  ╲__________╱  │ guia Y
         │  [ toolhead ]──┼── correias ancoram aqui
         │  ╱  viga X  ╲  │
         │ ╱            ╲ │
         ○╱              ╲○             (polias frontais)
```

- ΔA = ΔX + ΔY ; ΔB = ΔX − ΔY (Marlin: `COREXY`, suportado nativamente pela MKS TinyBee)
- **Reuso**: 2× NEMA17 XY, 2 polias motoras GT2 20T, 3 dos 4 trilhos MGN9×300 (2 guias Y + 1 viga X)
- **Comprar**: ~5 m de correia GT2 6 mm, ~8 polias desviadoras (idlers lisos Ø5 mm, ou rolamentos F695 empilhados), parafusos
- Motores ficam **fixos no quadro** (cantos traseiros) → menos massa móvel que qualquer alternativa
- Tensionamento simples: parafuso tensor na ancoragem do carro (estilo Voron)

> **Status: APROVADA pelo Leandro em 2026-10-03** (registro em [03-requisitos-e-decisoes.md](03-requisitos-e-decisoes.md)).

### Opção B — Cartesiano "Prusa de teto" / Markforged (H-Bot)

H-Bot usa 1 correia só, mas aplica momento de giro na viga X — exige trilhos lineares rígidos nos dois lados, senão trava/racking. Markforged complica os desvios. Sem vantagem real sobre CoreXY aqui. ❌

### Opção C — Ultimaker melhorado

Manter cinemática e só limpar o roteamento. Não resolve a insatisfação (as correias continuam chegando indiretamente ao toolhead) e continua consumindo ~160 mm de vão. ❌

## Arquitetura das guias (decidida 2026-10-03, revisada após confirmação dos 4× MGN9)

- **Y (2×)**: **trilhos MGN9×300 parafusados no topo dos perfis laterais** do anel XY — mantém o conceito da máquina atual (o Y já corre em MGN9 dos dois lados). Os carros Y são as **juntas XY estilo Voron**: peça impressa que une o carrinho Y à viga X **com as polias desviadoras encapsuladas dentro dela**, nos dois planos de correia — nada de polia exposta no topo
- **X (viga)**: **perfil 20×20 + trilho MGN (~300 mm) montado na face frontal** (estilo Voron/RatRig) — o perfil dá rigidez à viga, o trilho guia o toolhead. Montagem frontal (e não no topo) porque: placa do toolhead fica plana e parafusa direto no carrinho (sem "L" contornando a viga), o trilho fica mais perto do centro de massa do cabeçote (menos momento nas acelerações) e o topo da viga fica livre para esteira porta-cabos e endstop. Trilho fixado com parafusos M3 + porcas T no canal do perfil
- **Ancoragem das correias no toolhead**: as pontas das correias prendem na **traseira do carro do toolhead por ranhuras GT2 impressas** (o dente da correia morde a ranhura), uma ranhura em cada plano de correia, com canal de saída para o excedente — sem peça única de dois andares. Tensionamento puxando a ponta e recravando na ranhura (estilo Voron)

```
             topo livre (esteira)
            ┌──────────┐
   carrinho │  perfil  │
   MGN  ┌─┐ │  20×20   │
  ══════│█│▌│          │
 trilho └─┘ │          │
        │   └──────────┘
  placa │
  plana ├── extrusora/hotend (CG perto do trilho)
        │
```

## Dimensional (CoreXY, curso 200×200, números reais)

Anel de **440 mm externo** (vão interno 400 mm) — aprovado para compra em 2026-10-03. Com os trilhos MGN9×300 nos perfis laterais, o curso é limitado pelos trilhos, e 440 mm dão o espaço necessário para trilho + blocos de motor/polias nos cantos.

| Elemento | Valor | Observação |
|---|---|---|
| Anel XY (externo) | **440 × 440 mm** | Perfil 20×20 a comprar |
| Vão interno | 400 × 400 mm | Blocos de motor (traseira) e polias (frente) nos cantos |
| Guias Y | 2× MGN9×300 no topo dos perfis laterais | Trilho centrado: sobra 70 mm em cada ponta p/ os blocos de canto |
| Carro Y (cada lado) | placa ~45 mm sobre o carrinho MGN9 | Leva as polias de desvio das correias |
| Viga X | perfil 20×20 × **~360–400 mm** + MGN9×300 na face frontal | Comprimento exato no CAD; pontas parafusam nos carros Y |
| Curso X | ~255 mm disponíveis | Trilho 300 − carrinho (~29) − placa do toolhead; **precisa de 200** ✓ folga ~55 |
| Curso Y | ~250 mm disponíveis | Trilho 300 − placa do carro Y (~45); **precisa de 200** ✓ folga ~50 |
| Mesa 220×220 | cabe no vão de 400 | Torres Z posicionadas fora do caminho da mesa — CAD |

> As folgas de 50–55 mm absorvem o offset do bico, esteira porta-cabos e tensores sem aperto de projeto.
>
> Os perfis de **380 mm atuais ficam para travessas internas e a caixa da eletrônica**; os **630 mm continuam como colunas verticais** (torres Z + estrutura). Lista de corte definitiva sai do CAD.

## Z

O conceito do Z mudou para **guias MGN estilo Voron Trident** (2 colunas frontais + 1 central traseira, mesa em 3 pontos) — ver [06-conceito-z-voron.md](06-conceito-z-voron.md). As torres atuais com barras Ø8 são aposentadas.

## Lista de compras

Consolidada e pronta para pedido em [05-lista-de-compras.md](05-lista-de-compras.md).

## Perguntas em aberto

1. ~~Aprovação da Opção A (CoreXY)~~ ✅ aprovada 2026-10-03
2. ~~Fontes~~ ✅ 360 W + 120 W confirmadas
3. ~~Trilhos MGN~~ ✅ 4× MGN9×300 — 2 p/ Y, 1 p/ viga X, 1 reserva
4. ~~Perfis de 440 mm~~ ✅ compra aprovada 2026-10-03

Nenhuma pendência de conceito — próxima etapa é a modelagem do esqueleto no Fusion 360.

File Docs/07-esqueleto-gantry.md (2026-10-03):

# 07 — Esqueleto dimensional do gantry (CAD de referência)

Gerado programaticamente por [`CAD/scripts/esqueleto_gantry.py`](../CAD/scripts/esqueleto_gantry.py) (CadQuery/Python — paramétrico e versionado). Saídas:

- **`CAD/10-esqueleto-gantry_v1.step`** — montagem de referência do gantry CoreXY
- **`CAD/componentes/*.step`** — componentes padrão individuais (perfis, MGN9, NEMA17, polias, mesa MK3)

Os modelos são **envelopes dimensionais** (seções, cursos e interfaces corretos), não cosméticos. Servem de referência de posição para modelar as peças impressas por cima, no Fusion 360.

## Sistema de coordenadas (adotar o mesmo no Fusion!)

- **Origem**: centro do anel XY superior, em planta
- **Z = 0** no **topo** do anel superior; Z+ para cima
- **X+** para a direita; **Y+** para trás

## Empilhamento vertical (stack-up)

| z (mm) | O que está lá |
|---|---|
| −20 … 0 | Anel superior (perfis 20×20: laterais 440, frente/trás 400) |
| 0 … 6,5 | Trilhos MGN9×300 do Y (sobre os perfis laterais, centrados em y=0) |
| 0 … 10 | Carrinhos MGN9 do Y (topo em z=10) |
| 10 … 48 | **Juntas XY** (caixa âmbar translúcida no STEP — as polias desviadoras ficam **dentro** delas) |
| 15 … 35 | Viga X (perfil 20×20 × **340 mm**, entre as faces internas das juntas em x=±175, folga 5 mm/lado) |
| 17 … 23 | **Plano de correia B** (inferior) |
| 27 … 33 | **Plano de correia A** (superior) |
| — | Trilho MGN9×300 do X na **face frontal** da viga (y −10 … −16,5); carrinho até y=−20; placa do toolhead y −20 … −24 |

## Posições-chave (em planta)

| Elemento | Posição |
|---|---|
| Centros dos perfis laterais / trilhos Y | x = ±210 |
| Motores A (esq.) e B (dir.) | (±185, +182), corpo acima, eixo p/ baixo, polia 20T no plano da sua correia |
| Polias desviadoras dianteiras | (±185, −185), uma por plano em cada canto |
| Faces internas das juntas XY | x = ±175 |
| **Bico** (marcador vermelho) | offset de **−35 mm em Y** do centro da viga |
| **Centro útil da mesa** | **(0, −35)** — a mesa fica deslocada 35 mm para a frente do centro do anel |

## Verificação de cursos (impressa pelo script a cada execução)

| Grandeza | Valor | Requisito |
|---|---|---|
| Curso X do bico | **261,5 mm** (±130,8) | 200 ✓ (folga +30,8/lado) |
| Curso Y do bico | **261,5 mm** (−165,8 … +95,8) | 200 ✓ (folga +30,8/lado) |
| Janela 200×200 centrada em (0, −35) | coberta | ✓ |
| Correia por loop | ~2,17 m (2 loops ≈ 4,35 m) | rolo de 5 m ✓ |

> O offset de −35 do bico é **estimado** (espessura da placa + corpo do hotend). Quando o toolhead real for modelado, atualizar `BICO_OFFSET_Y` em [`parametros.py`](../CAD/scripts/parametros.py) e rodar o script de novo — as asserções garantem que os 200×200 continuam cobertos.

## Como regenerar / usar

```powershell
# uma vez por máquina:
py -3.12 -m venv C:\Reprap\.venv
C:\Reprap\.venv\Scripts\pip install -r C:\Reprap\CAD\scripts\requirements.txt

# gerar (de dentro de CAD/scripts/):
C:\Reprap\.venv\Scripts\python.exe esqueleto_gantry.py
```

**No Fusion 360**: `File → Open → selecionar o .step` (ou *Insert → Insert CAD*). Fixar (`Ground`) os perfis do anel e modelar as peças impressas referenciando as faces do esqueleto. Exportar os resultados (F3D+STEP) de volta para `CAD/`.

## O que o esqueleto ainda NÃO contém (próximas iterações)

1. Colunas verticais, anel da base e coluna central traseira do Z (depende da aprovação da Opção A de acionamento — [06](06-conceito-z-voron.md))
2. Polias internas das juntas XY e trajeto fino das correias (fase de detalhamento das peças impressas)
3. Toolhead real (extrusora vermelha + hotend) — falta identificar os modelos ([inventário](01-inventario-componentes.md))

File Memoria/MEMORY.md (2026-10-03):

- [Visão geral do projeto RepRap](reprap-visao-geral.md) — repo C:\Reprap→github lsrtorres/Reprap; memória real vive em Docs/ do repo; 200³, Fusion 360
- [Perfil do Leandro](leandro-perfil.md) — PT-BR, tem a máquina em mãos, colaboração via git

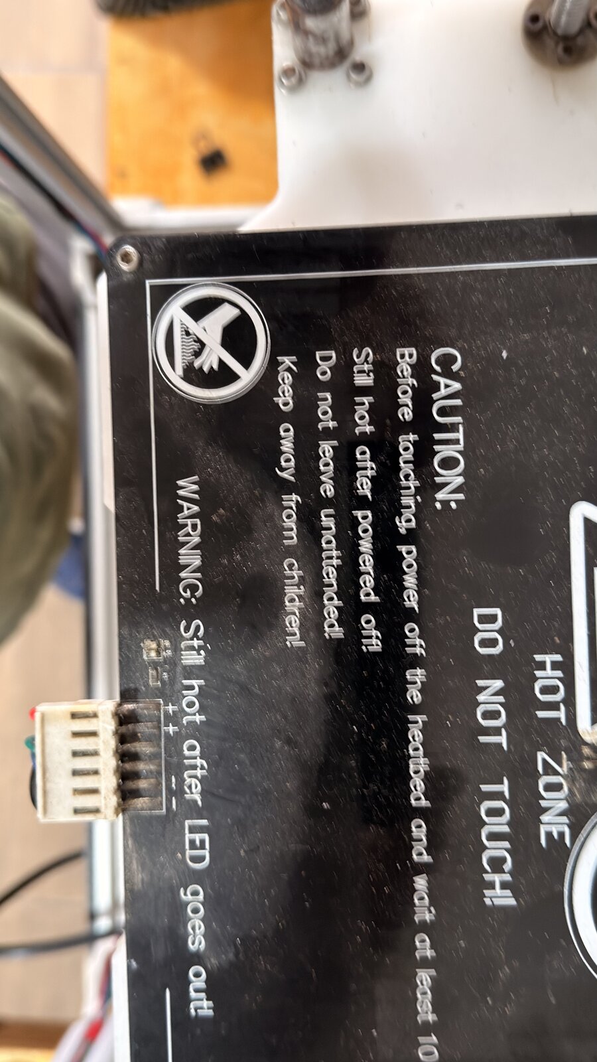
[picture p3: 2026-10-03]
Fotos/jpg/mesa.jpg

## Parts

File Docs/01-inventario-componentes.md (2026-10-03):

# 01 — Inventário de componentes (a reaproveitar)

Levantamento feito a partir das fotos de 2026-10-03 (`Fotos/jpg/`) + medições do Leandro (2026-10-03). Itens marcados com ❓ precisam ser confirmados/medidos na máquina física.

## Eletrônica

| Item | Identificação | Status |
|---|---|---|
| Placa controladora | **MKS TinyBee V1.0** (Makerbase, ESP32 com WiFi, 5 slots de driver) — será substituída pela **MKS Monster8 V2** (8 slots) e vira reserva ([decisão](03-requisitos-e-decisoes.md)) | Confirmado (IMG_0322) |
| Drivers de passo | **5× TMC2209** (removíveis, dissipador azul) — no Klipper rodarão em modo UART | Confirmado (Leandro) |
| Fonte 1 | **ST-120-12** — **12 V 10 A (120 W)**, fab. 2021 | Confirmado (IMG_0322 + Leandro) |
| Fonte 2 | Fonte chaveada prata maior — **12 V 30 A (360 W)** | Confirmado (Leandro) |
| MOSFET externo | Módulo preto para mesa aquecida, com borne parafusado | Confirmado (IMG_0321/0322) |
| Distribuição | Conectores WAGO tipo 221 (5 vias) ×2 | Confirmado (IMG_0321) |
| Display | Tela em caixa impressa branca no meio da torre — ❓ modelo (MKS TFT? 12864?) | A confirmar (IMG_0317) |
| Ventoinhas | 2× fans (~40–50 mm) no painel da base | Confirmado (IMG_0323) |
| Endstops | Pelo menos 1 endstop em PCB (suporte verde no Z) — ❓ quantidade/tipo | A confirmar (IMG_0325) |

## Motores

| Item | Qtde | Observação |
|---|---|---|
| NEMA 17 | **5** (X, Y, 2× Z, extrusora) — um deles etiquetado "5" | ❓ confirmar modelo/corrente (etiqueta dos motores) |

## Movimento

| Item | Identificação | Status |
|---|---|---|
| Gantry XY | Estilo Ultimaker: eixos cruzados com correias GT2 no perímetro, blocos deslizantes impressos | Confirmado (IMG_0320/0325/0326/0328) |
| Trilho linear | **4× trilho MGN9 (9 mm) × 300 mm** com carrinho (tampas verdes) | Confirmado (Leandro) |
| Eixos lisos (torres Z) | Barras retificadas **Ø8 mm × ~400 mm**, 2 por torre (4 no total) — únicos eixos em barra da máquina; o gantry XY é todo em MGN9 | Confirmado (Leandro) |
| Fusos Z | 2 fusos **trapezoidais TR8** verticais (torres esq./dir.), acionados por cima, porca de bronze — ❓ passo/avanço (TR8×8? ×2?) e comprimento | Confirmado (Leandro) |
| Curso XY atual | **~180 mm** em X e Y (limite do quadro atual de 380 mm) | Confirmado (Leandro) |
| Correias | GT2 6 mm com polias e esticadores | Confirmado (IMG_0320/0328) |
| Esteira porta-cabos | Esteira impressa branca para o cabeçote | Confirmado (IMG_0318/0328) |

## Cabeçote / Extrusão

| Item | Identificação | Status |
|---|---|---|
| Extrusora | Direct-drive com corpo vermelho sobre o carro central | Confirmado (IMG_0317) — ❓ modelo |
| Hotend | Montado sob o carro, envolto em fita preta — ❓ modelo (E3D V5/V6 clone? MK8?) | A confirmar (IMG_0326) |

## Mesa de impressão

| Item | Identificação | Status |
|---|---|---|
| Superfície | Vidro com clipes | Confirmado (IMG_0317) |
| Mesa aquecida | **MK3 de alumínio, 220 × 220 mm**, alimentação 12 V, conector de bloco + LED indicador | Confirmado (Mesa.heic + Leandro) |
| Suporte | Plataforma impressa branca com molas de nivelamento (4 pontos) | Confirmado (IMG_0317/0325) |

## Estrutura

| Item | Identificação | Status |
|---|---|---|
| Perfis de alumínio | **20×20 mm**, ranhura p/ porca T M5 — comprimentos disponíveis: **380 mm** e **630 mm**; compra de perfis adicionais aprovada | Confirmado (Leandro) |
| Fixação | Cantoneiras/placas impressas externas, parafusos M5 + porca T | Confirmado (IMG_0317/0318) |
| Painéis | Chapas perfuradas brancas na base (compartimento da eletrônica) | Confirmado (IMG_0321/0322) |

## Medições pendentes (fazer na máquina)

Nenhuma pendência bloqueia o gantry XY. As restantes são para as fases Z e eletrônica:

1. Modelo/corrente dos motores NEMA 17 (etiqueta lateral)
2. Modelo do display
3. Modelo da extrusora vermelha (o hotend será substituído por V6 Volcano — [decisão](03-requisitos-e-decisoes.md); fusos TR8 atuais viram reserva, substituídos por TR8×8 novos)
4. Quantos perfis de **380 mm** existem no estoque (630: confirmado **4**, todos usados inteiros como colunas; a 5ª coluna é um 440 comprado)

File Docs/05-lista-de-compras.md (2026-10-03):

# 05 — Lista de compras (gantry CoreXY + Z)

Consolidada em 2026-10-03 após aprovação dos conceitos ([04](04-conceito-novo-gantry.md), [06](06-conceito-z-voron.md)) e do anel de 440 mm.

> ⚠️ **Correção final 2026-10-03** (derivada do esqueleto CAD — [Docs/08](08-esqueleto-maquina.md)): só o **anel superior** usa perfis de 440 nas laterais; os anéis da **base** e do **deck** ficam **entre** as colunas dos cantos, então são todos de 400. Total: **2× 440 + 11× 400**. As colunas são 5× 630 do estoque (4 inteiras + 1 cortada em 440).

## Pedido principal

| # | Item | Especificação | Qtde | Uso |
|---|---|---|---|---|
| 1 | Perfil alumínio 20×20 T-slot (canal 6) | **440 mm** | **3** | 2× laterais do anel XY superior + 1× **coluna Z central traseira** (estoque tem só 4× 630, usados inteiros nos cantos) |
| 2 | Perfil alumínio 20×20 T-slot (canal 6) | **400 mm** | **11** | Frente/trás do anel superior (2) + anel do deck (4) + anel da base (4) + viga X (1, cortar em 340) |
| 3 | Correia GT2 largura 6 mm (aberta) | **5 m** | 1 rolo | 2 loops CoreXY (~2,1 m cada) + sobra |
| 4 | Polia idler GT2 **lisa** 20 dentes equiv., furo 5 mm, p/ correia 6 mm | — | **6** | Desvios onde o **dorso** da correia toca |
| 5 | Polia idler GT2 **dentada** 20T, furo 5 mm, p/ correia 6 mm | — | **4** | Desvios onde o **lado dentado** toca |
| 6 | Porca T (martelo) M3, canal 6, perfil 20×20 | — | **60** | Fixação dos 3 trilhos MGN9 (15 furos/trilho, passo 20 mm) + reserva |
| 7 | Parafuso M3×8 cabeça cilíndrica (allen) | — | **50** | Trilhos MGN9 nos perfis |
| 8 | Parafuso M3×10/12 + M3 porca | — | **~20** | Carrinhos MGN9 → placas dos carros (conferir comprimento no CAD) |
| 9 | Parafuso M5×25/30 (eixo das polias idler) | — | **10** | Postes das polias nas juntas XY e blocos de motor |

## Fase Z (conceito [06](06-conceito-z-voron.md))

| # | Item | Especificação | Qtde | Uso |
|---|---|---|---|---|
| 10 | Trilho linear **MGN9 × 300 mm com carrinho** | padrão (ex.: MGN9C) | **2** | Guias Z frontais (a traseira usa o 4º trilho do estoque) |
| 11 | **BLTouch** (original ou clone 3DTouch) | sonda de pino (vidro exige pino; indutiva não serve) | **1** | `G34` (auto-alinhamento dos 2 fusos) + malha `G29`; a TinyBee tem porta 3D-Touch |
| 12 | Porca T M3 + parafuso M3×8 | adicionais aos do item 6/7 | **+40** | Fixação dos 3 trilhos Z nas colunas |
| 13 | Acoplador flexível 5×8 mm | se os atuais não forem reaproveitáveis | 1–3 | Motor → fuso TR8 (conferir estoque; precisamos de 3) |
| 14 | **Fuso TR8 × 400 mm, passo 8 mm** (TR8×8, 4 entradas) **+ castanha de bronze** | kit fuso+castanha | **3** | Trident completo: frontal-esq., frontal-dir. e central traseiro |
| 15 | **Mancal KP08 ou KFL08** (eixo Ø8) | com rolamento | **3** | Apoio dos fusos na base (motor embaixo, estilo Trident) |
| 16 | **Hotend V6 com bloco Volcano** | ⚠️ versão **12 V** (cartucho 40 W 12 V + termistor) — muitos kits vêm 24 V | **1** | Novo cabeçote; substitui o hotend atual envolto em fita |
| 17 | **Placa MKS SKIPR** | SoC quad-core (Klipper host **embutido**) + MCU STM32, 7 slots de driver, 12–24 V; conferir se o kit inclui dongle WiFi USB (senão, usar Ethernet) + cartão microSD ≥16 GB p/ a imagem | **1** | Substitui a TinyBee (vira reserva); host + MCU numa placa só |
| 18 | **Motor NEMA17** | similar aos atuais (~40 mm, 1,5–1,7 A; confirmar etiqueta dos existentes) | **1** | 3º fuso Z |
| 19 | **Driver TMC2209** | igual aos 5 atuais (confirmado: a máquina já usa TMC2209) — modo UART no Klipper | **1** | 6º slot da SKIPR |
| 20 | Acelerômetro **ADXL345** (opcional) | com cabo (a SKIPR tem porta SPI p/ ele) | 0–1 | Calibração do input shaper — onde o Klipper brilha no CoreXY |

## Conferir no estoque antes de comprar (já devem existir)

- Parafusos M5×8/10 + porcas T M5 (cantoneiras do quadro) — padrão atual da máquina
- Cantoneiras externas — serão substituídas/complementadas por peças impressas novas
- Polias motoras GT2 20T furo 5 mm — **reuso das 2 atuais**
- LM8UU — ~~não são mais necessários para o gantry~~ (guias Y agora usam MGN9)

## Observações de compra

- **Perfis**: pedir já cortados no tamanho (fornecedores de perfil estrutural cortam sob medida). Tolerância de corte ±0,5 mm é suficiente; o esquadro vem das peças impressas de canto.
- **Idlers**: alternativa aos itens 4–5 são rolamentos F695ZZ aos pares (mais baratos, montagem em parafuso M5), mas as polias prontas com flange alinham melhor a correia de 6 mm.
- **Correia**: preferir GT2 com reforço de fibra de vidro; evitar as com alma de aço (raio mínimo de curvatura maior).

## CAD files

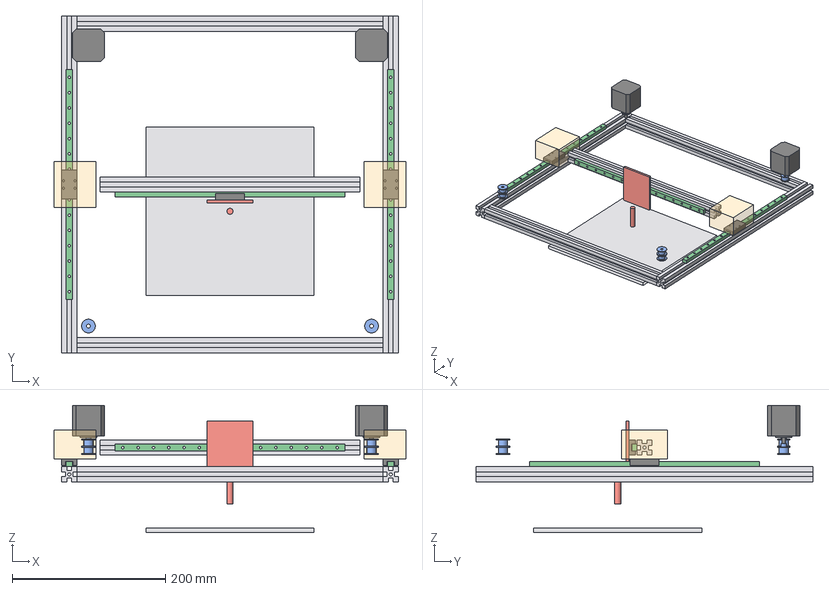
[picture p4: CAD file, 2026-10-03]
CAD/10-esqueleto-gantry_v1.step
460.0 x 440.0 x 166.0 mm
perfil-esq
perfil-dir
perfil-frente
perfil-tras
trilho-y-esq
carrinho-y-esq
junta-xy-esq
trilho-y-dir
carrinho-y-dir
junta-xy-dir
viga-x
trilho-x
carrinho-x
toolhead-placa
bico-marcador
motor-a
polia-motor-a
motor-b
polia-motor-b
idler-frente-esq-a
idler-frente-esq-b
idler-frente-dir-a
idler-frente-dir-b
mesa-mk3-referencia

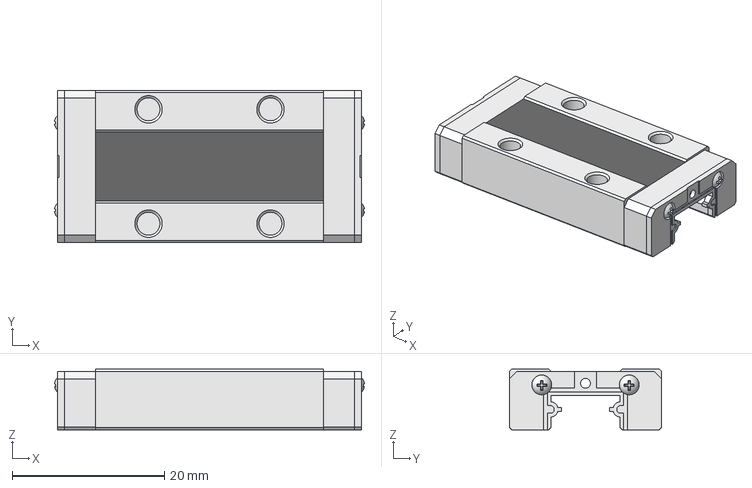
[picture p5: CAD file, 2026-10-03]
CAD/componentes/mgn9h-carrinho-hiwin.step
40.7 x 20.0 x 8.00 mm

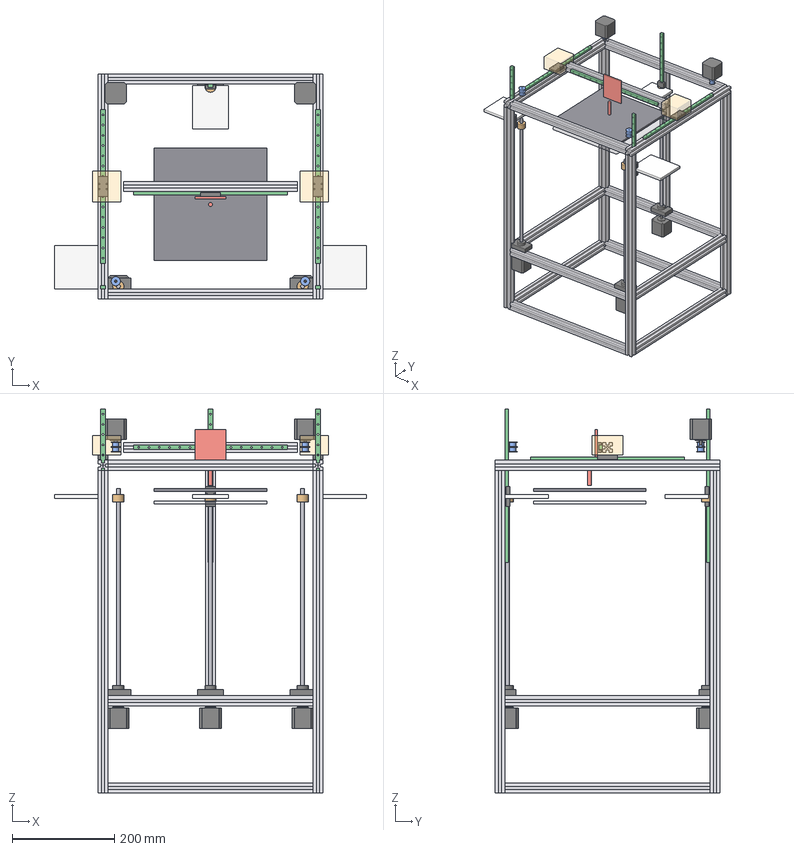
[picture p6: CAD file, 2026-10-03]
CAD/11-esqueleto-maquina_v1.step
610.0 x 440.0 x 750.0 mm
perfil-esq
perfil-dir
perfil-frente
perfil-tras
trilho-y-esq
carrinho-y-esq
junta-xy-esq
trilho-y-dir
carrinho-y-dir
junta-xy-dir
viga-x
trilho-x
carrinho-x
toolhead-placa
bico-marcador
motor-a
polia-motor-a
motor-b
polia-motor-b
idler-frente-esq-a
idler-frente-esq-b
idler-frente-dir-a
idler-frente-dir-b
mesa-mk3-referencia
coluna-0
coluna-1
coluna-2
coluna-3
coluna-z-tras
base-lateral-esq
base-lateral-dir
base-frente
base-tras
deck-lateral-esq
deck-lateral-dir
deck-frente
deck-tras
trilho-z-esq
carrinho-z-esq
trilho-z-dir
carrinho-z-dir
trilho-z-tras
carrinho-z-tras
fuso-z0
castanha-z0
mancal-kp08-z0
motor-z0
fuso-z1
castanha-z1
mancal-kp08-z1
motor-z1
fuso-z2
castanha-z2
mancal-kp08-z2
motor-z2
braco-esq
braco-dir
braco-tras
mesa-mk3-home

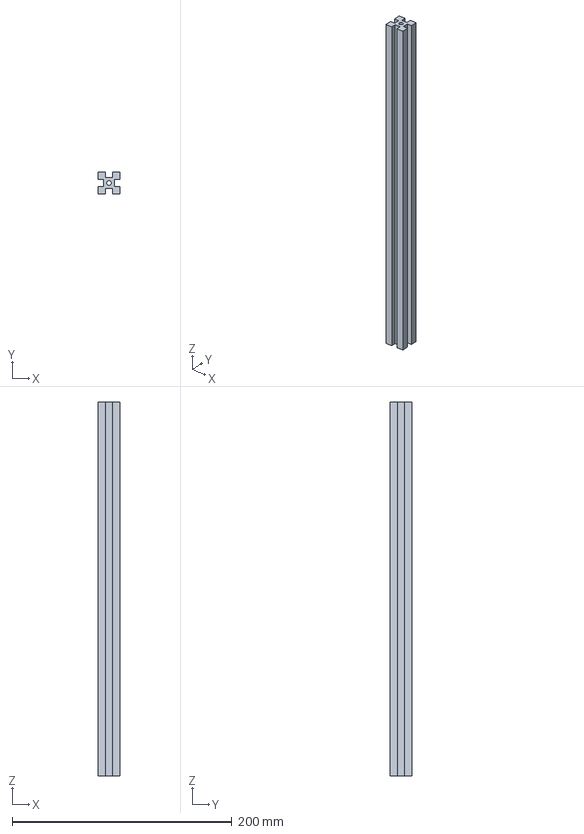
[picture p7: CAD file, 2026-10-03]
CAD/componentes/perfil-2020-340-viga-x.step
20.0 x 20.0 x 340.0 mm

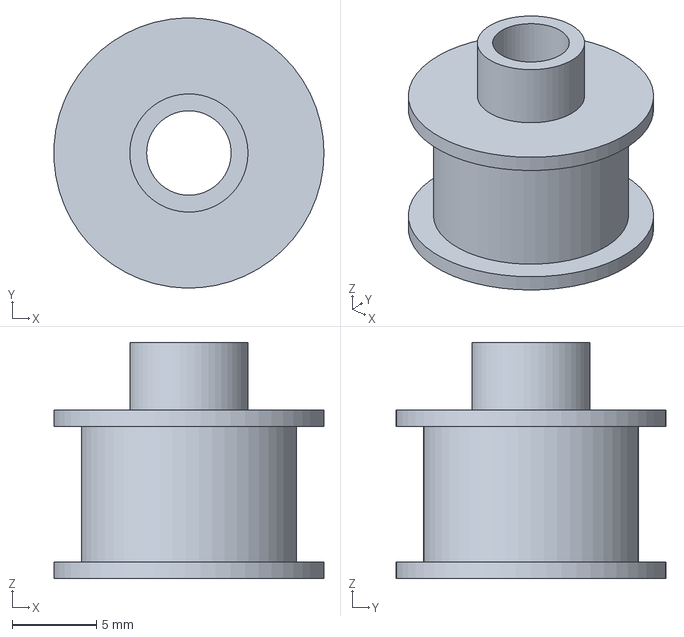
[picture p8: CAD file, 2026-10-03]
CAD/componentes/polia-gt2-20t.step
16.0 x 16.0 x 14.0 mm

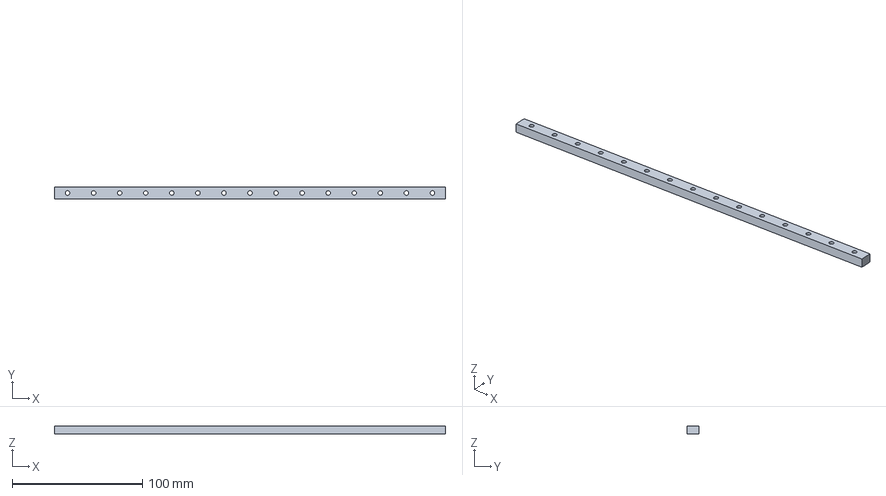
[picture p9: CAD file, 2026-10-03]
CAD/componentes/mgn9-trilho-300.step
300.0 x 9.00 x 6.50 mm

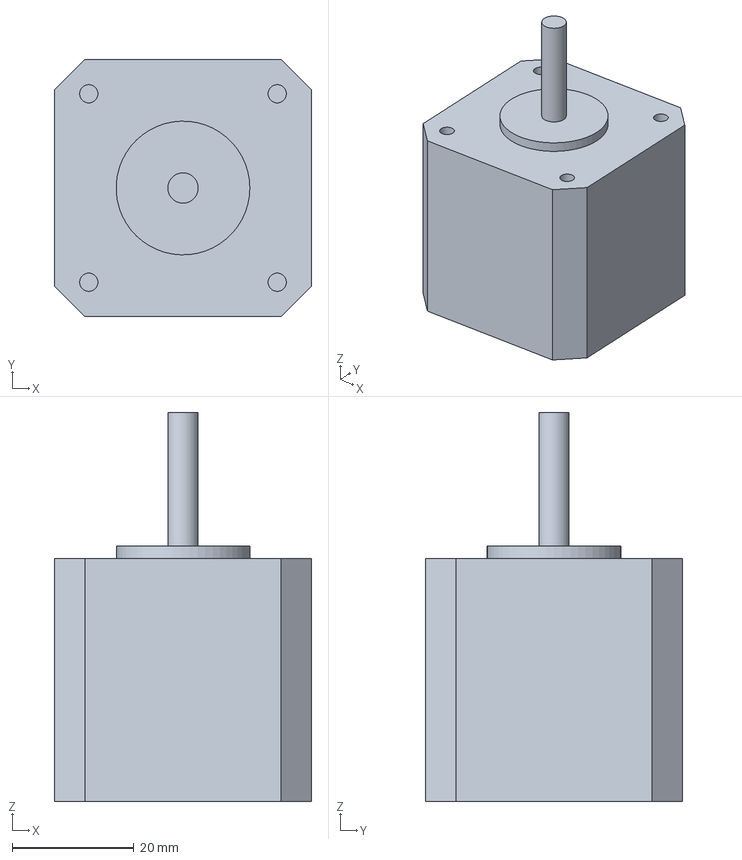
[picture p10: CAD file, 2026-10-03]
CAD/componentes/nema17.step
42.3 x 42.3 x 64.0 mm

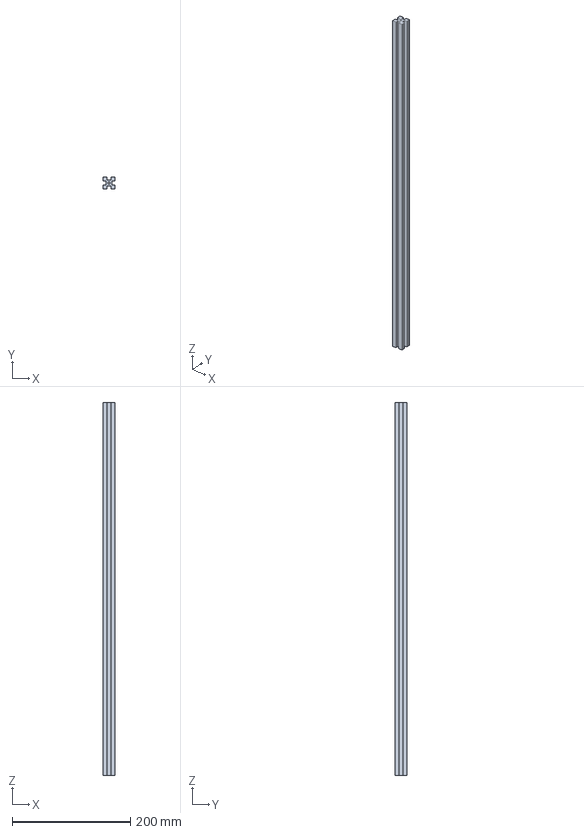
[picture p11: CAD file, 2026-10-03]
CAD/componentes/perfil-2020-630.step
20.0 x 20.0 x 630.0 mm

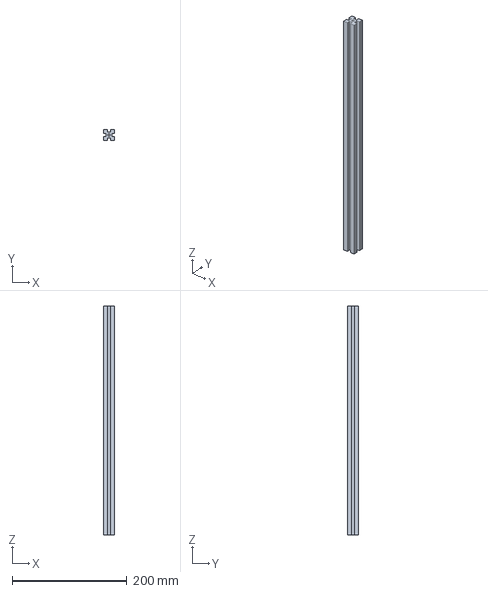
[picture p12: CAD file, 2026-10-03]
CAD/componentes/perfil-2020-400.step
20.0 x 20.0 x 400.0 mm

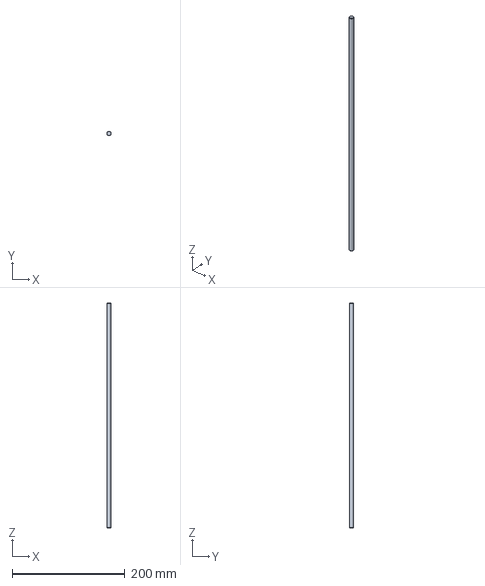
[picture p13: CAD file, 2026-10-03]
CAD/componentes/fuso-tr8x8-400.step
7.99 x 8.00 x 400.0 mm

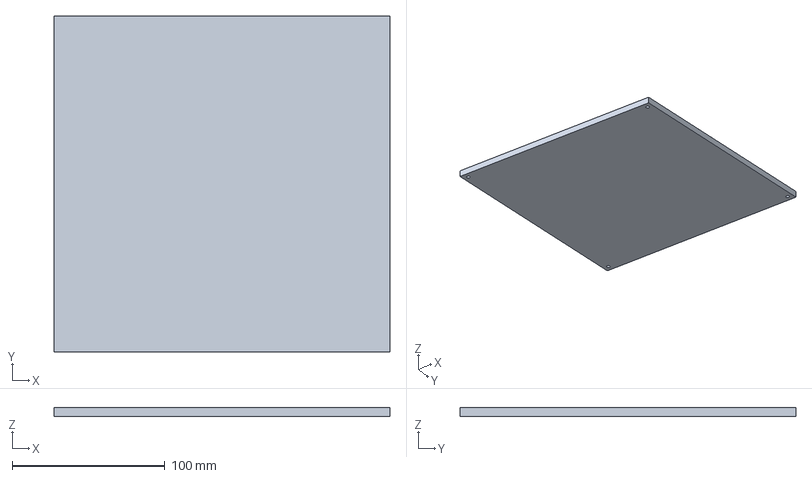
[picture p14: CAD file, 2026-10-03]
CAD/componentes/mesa-mk3-220.step
220.0 x 220.0 x 6.00 mm

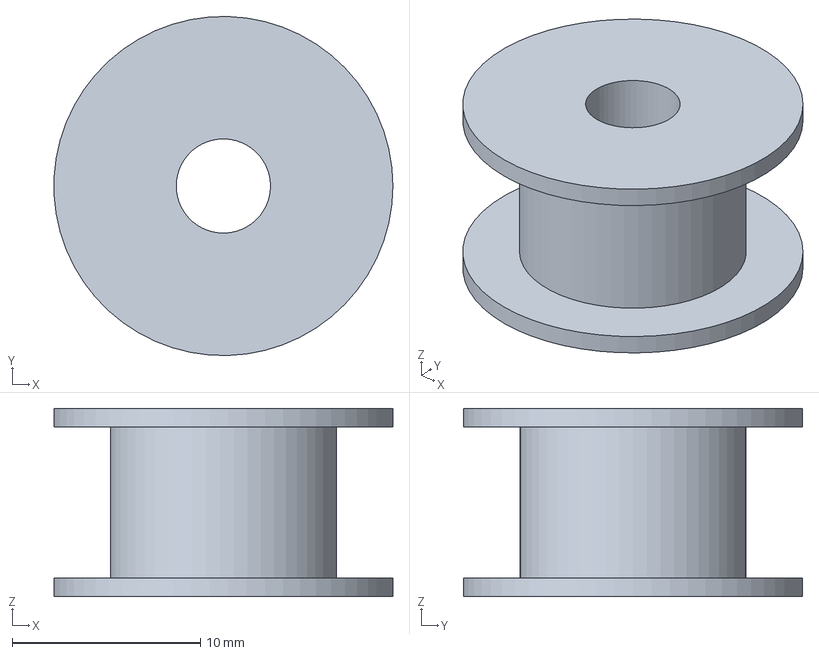
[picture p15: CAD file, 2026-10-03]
CAD/componentes/idler-20t.step
18.0 x 18.0 x 10.0 mm

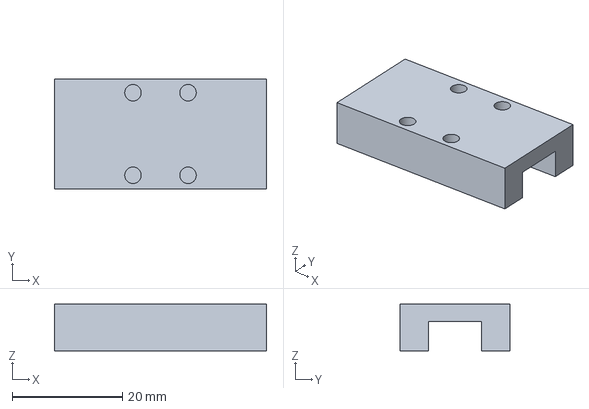
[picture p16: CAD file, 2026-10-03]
CAD/componentes/mgn9-carrinho.step
38.5 x 20.0 x 8.50 mm

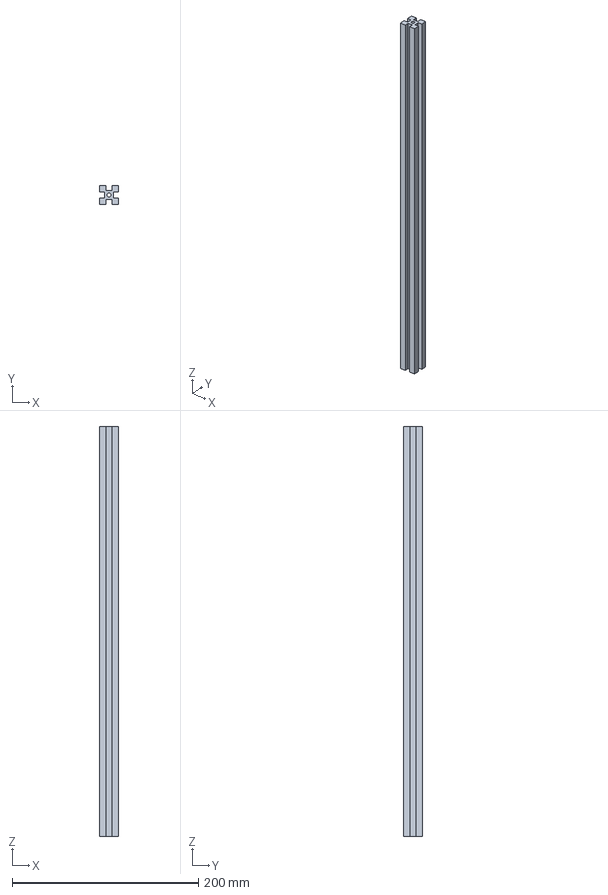
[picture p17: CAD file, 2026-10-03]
CAD/componentes/perfil-2020-440.step
20.0 x 20.0 x 440.0 mm

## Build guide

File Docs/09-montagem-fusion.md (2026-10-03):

# 09 — Montagem peça a peça no Fusion 360 (juntas + simulação)

Objetivo: montar a impressora no Fusion com componentes reais, **juntas rígidas + sliders**, e testar os movimentos (cursos, colisões) antes de comprar/imprimir qualquer peça.

Sistema de coordenadas: o mesmo de todo o projeto ([07](07-esqueleto-gantry.md)/[08](08-esqueleto-maquina.md)) — origem no centro do anel superior, z=0 no topo do anel, X+ direita, Y+ trás.

## Fluxo de incorporação (upload → inserir, um a um)

1. **Upload**: no Data Panel do Fusion, subir cada `.step` de `CAD/componentes/` (e os de fabricante) para a pasta do projeto — cada um vira um **componente na nuvem com versionamento próprio**;
2. **Inserir**: na montagem, botão direito no item → *Insert into Current Design* — o componente entra **vinculado (X-ref)**;
3. **Posicionar** com *Move/Align* usando a tabela de posições abaixo — ou inserir o `11-esqueleto-maquina_v1.step` como gabarito temporário, dar `Ground`, encaixar as peças nele e depois ocultá-lo/removê-lo;
4. **Atualização**: quando um STEP for regenerado pelos scripts (dimensão de conceito mudou), fazer upload **como nova versão do mesmo item** (mesmo nome, mesma pasta) — o Fusion marca o link como desatualizado na montagem e atualiza com um clique. Por isso os nomes de arquivo são estáveis;
5. Manter o nome do arquivo como nome do componente, para a árvore da montagem bater com os documentos.

## Divisão dos STEPs

### Gerados por script (já em `CAD/componentes/`)

| Arquivo | Peça | Usos |
|---|---|---|
| `perfil-2020-630.step` | coluna | 4× cantos |
| `perfil-2020-440.step` | lateral do anel / coluna Z traseira | 2× + 1× |
| `perfil-2020-400.step` | membro de anel | 10× (2 anel sup. + 4 deck + 4 base) |
| `perfil-2020-340-viga-x.step` | viga X | 1× |
| `mgn9-trilho-300.step` | trilho MGN9 (a "régua", sem carrinho) | 6× (2 Y, 1 X, 3 Z) |
| `fuso-tr8x8-400.step` | fuso TR8×8 (cilindro liso — rosca não modelada) | 3× |
| `nema17.step`, `polia-gt2-20t.step`, `idler-20t.step`, `mesa-mk3-220.step` | placeholders dimensionais | — |

### Você traz do fabricante (STEP comercial)

| Peça | Qtde | Onde achar |
|---|---|---|
| **Carrinho MGN9C** (patins) | 6 | Site da HIWIN (CAD download), TraceParts, GrabCAD |
| **Mancal KP08** (ou KFL08) | 3 | GrabCAD, TraceParts, 3DContentCentral |
| **Castanha T8 flangeada** (bronze) | 3 | GrabCAD ("T8 brass nut") |
| Opcionais p/ realismo: NEMA17, V6 Volcano, BLTouch, SKIPR | — | GrabCAD; a MKS publica desenhos no GitHub (makerbase-mks) |

> Dica: confira se o MGN9C baixado tem **38,5 mm de comprimento × 20 de largura × altura 10 da base do trilho** — é o que o esqueleto assume.

## Posições das peças de fabricante (máquina em **home**)

| Peça | Instâncias | Posição do centro (x, y, z) | Orientação |
|---|---|---|---|
| MGN9C nos trilhos Y | 2 | (−210, 0, topo a z=10) e (+210, 0, idem) | desliza em **Y** |
| MGN9C no trilho X | 1 | (0, −15, 25) | desliza em **X**, montado na face frontal da viga |
| MGN9C nos trilhos Z frontais | 2 | (−210, −195, −71) e (+210, −195, −71) | desliza em **Z**, face p/ trás |
| MGN9C no trilho Z traseiro | 1 | (0, +195, −71) | desliza em **Z**, face p/ frente |
| Castanha T8 | 3 | (−180, −195), (+180, −195), (0, +195) — flange no topo do braço, z = **−67** | eixo vertical |
| Mancal KP08 | 3 | mesmos (x, y) das castanhas, base sobre o deck em z = **−460** | eixo vertical |
| Fuso TR8×8×400 | 3 | mesmos (x, y), de z −455 a −55 | vertical |
| NEMA17 do Z | 3 | mesmos (x, y), corpo de z −524 a −484, eixo p/ cima | na baia, sob o deck |
| NEMA17 A/B | 2 | (−185, +182) e (+185, +182), corpo de z 40 a 80, eixo p/ baixo | cantos traseiros |

## Receita de juntas no Fusion

1. **Rigid Group "frame"**: todos os perfis + trilhos + mancais + motores (tudo que não se move)
2. **Rigid Group "leito"**: mesa + 3 braços + 3 castanhas + 3 carrinhos Z
3. **Sliders** (*Joint → Slider*, usar *As-Built Joint* com a peça já posicionada):
   | Junta | Entre | Eixo | Limites |
   |---|---|---|---|
   | Y-esq / Y-dir | carrinho MGN9C ↔ trilho Y | Y | **±130,75 mm** |
   | X | carrinho MGN9C ↔ trilho X | X | **±130,75 mm** |
   | Z | grupo "leito" ↔ trilho Z (1 slider basta; os outros 2 carrinhos já vão juntos pelo grupo) | Z | **0 a −200** (do home) |
4. **Viga X**: rigid entre viga + juntas XY + os 2 carrinhos Y (ela acompanha o Y e carrega o trilho X)
5. **Fusos (opcional, bonito na simulação)**: *Revolute* fuso↔mancal + **Motion Link** revolute↔slider Z com **8 mm por volta** (passo do TR8×8)
6. **Colisões**: *Assemble → Enable Contact Sets* nos pares críticos (mesa × colunas, juntas XY × cantos) e arrastar as juntas pelos limites

> **Nota CoreXY**: a cinemática real (ΔA=ΔX+ΔY etc.) vem das correias, que não são modeláveis como junta no Fusion. Para validar cursos e colisões, os dois sliders independentes (X e Y) são exatamente equivalentes — o que a correia muda é *quem* gira, não *onde* o carro chega.

## Checagens que a simulação deve confirmar

- [ ] Bico varre 200×200 centrado em (0, −35) sem a junta XY tocar os cantos
- [ ] Mesa desce 200 sem tocar deck/mancais (fim de curso do braço em z −267; mancal a −460 ✓ folga ~190)
- [ ] Esteira porta-cabos e cabos do toolhead (quando modelados) não interferem no curso Y
- [ ] Castanha nunca alcança a ponta do fuso (+12 mm de sobra no topo em home)

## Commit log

2026-10-03 Estrutura inicial do projeto: docs, fotos e organizacao do repositorio
    - README com objetivos (volume 200x200x200, reaproveitamento total) e fluxo de CAD
    - Docs/01: inventario de componentes identificados nas fotos + medicoes pendentes
    - Docs/02: analise da maquina atual (estilo Ultimaker, Z por torres com fuso)
    - Docs/03: requisitos e registro de decisoes
    - Fotos originais HEIC + conversoes JPG 1600px para visualizacao no GitHub
    - Estrutura CAD/ para exportacoes do Fusion 360
2026-10-03 Medicoes do Leandro + conceito CoreXY para o novo gantry (Docs/04)
    - Inventario: perfil 20x20, barras 8x300, fusos TR8, mesa MK3 220x220 12V
    (foto Mesa.heic), curso XY atual ~180mm; flag de divergencia na fonte
    ST-120-12 (etiqueta 10A vs informado 30A)
    - Novo requisito R8: correias chegando direto ao toolhead e ao gantry
    - Docs/04: comparacao CoreXY vs H-Bot vs Ultimaker melhorado, dimensional
    preliminar (anel XY ~420mm), rascunho da lista de compras
    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
2026-10-03 CoreXY aprovado; dimensional fechado em torno das barras Y de 400mm
    - Decisoes ativas: CoreXY, viga X = perfil 20x20 + trilho MGN,
    guias Y = 2x barra 8x400 com LM8UU, divisao de fontes 360W/120W
    - Inventario: fontes confirmadas (360W + 120W), barras 8x~400mm,
    trilho MGN ~8mm largura (provavel MGN9)
    - Docs/04: anel XY proposto de 440mm externo (vao 400 recebe as barras
    sem corte), cursos calculados X~260/Y~275 para 200 necessarios,
    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
2026-10-03 Memoria do assistente versionada no repo (pasta Memoria/)
    Diretorio de memoria do Claude Code agora e uma junction NTFS para
    Memoria/ dentro do repositorio: toda atualizacao de memoria entra nos
    commits. README documenta como recriar a junction em outra maquina.
2026-10-03 Trilho MGN na face frontal da viga X (estilo Voron), nao no topo
    Sugestao do Leandro: placa do toolhead plana parafusada direto no
    carrinho, CG do cabecote mais perto do trilho (menos momento nas
    aceleracoes) e topo da viga livre para esteira e endstop.
2026-10-03 4x MGN9x300 confirmados: guias Y migram para trilhos; lista de compras final
    - Inventario: 4 trilhos MGN9 de 300mm confirmados; pendencias restantes
    sao so da fase Z/eletronica
    - Decisao: guias Y = 2x MGN9 nos perfis laterais (substitui barras 8x400,
    que viram reserva); anel 440mm aprovado para compra pelo Leandro
    - Docs/04: dimensional revisado (cursos X~255 / Y~250 para 200 necessarios)
    - Docs/05: lista de compras consolidada pronta para pedido (perfis, correia
    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
2026-10-03 Conceito Z Voron + esqueleto CAD parametrico do gantry + hardware do Z definido
    - Docs/06: Z estilo Voron Trident (3 guias MGN: 2 frontais + 1 central
    traseira); analise de acionamento com a restricao de 5 slots da TinyBee;
    Opcao A confirmada: 2 fusos frontais (G34) + seguidor traseiro
    - Hardware Z especificado pelo Leandro: TR8x8 400mm + castanhas bronze,
    mancais KP08/KFL08, motores embaixo, BLTouch; hotend novo V6 Volcano 12V
    - Juntas XY estilo Voron (polias encapsuladas) e ancoragem de correia por
    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
    [10-esqueleto-gantry_v1.step, idler-20t.step, mesa-mk3-220.step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]
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2026-10-03 Firmware: Klipper (Monster8 V2 como MCU); ajustes na lista de compras
    - Decisao do Leandro (ja opera outra RepRap com Klipper); TinyBee/ESP32
    nem roda Klipper, a troca de placa ja estava certa
    - Z_TILT_ADJUST 3 pontos + BED_MESH com BLTouch no lugar do G34
    - Display MKS TFT vira reserva (UI Mainsail/Fluidd); modulo MKS WiFi
    cancelado; itens de host (2a instancia/Pi/SKIPR) e ADXL345 opcionais
    - Firmware/README.md com as sementes do printer.cfg (corexy,
    rotation_distance XY=40 / Z=8, 6 steppers, z_tilt)
    - Decisao aberta: host do Klipper
2026-10-03 Placa definida: MKS SKIPR (Klipper host embutido + MCU, 7 slots)
    Substitui a Monster8 V2 decidida horas antes: com firmware fechado em
    Klipper, o Leandro escolheu a placa com host embutido - sem Pi externo,
    sem buck 5V. 6 slots usados (X, Y, 3xZ, E) + 1 folga. Lista de compras,
    conceito Z, firmware e memoria atualizados.
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2026-10-03 Esqueleto da maquina completa: frame vertical + Z Trident validados
    - CAD/scripts/esqueleto_maquina.py: colunas (4x630 + 1 cortada), anel da
    base, deck da eletronica (baia 150mm), 3 trilhos Z MGN9x300, 3 fusos
    TR8x8x400 com castanha/mancal/motor, bracos e mesa rigida em 3 pontos
    - Verificacoes automaticas passam: fuso 400 cobre o curso Z de 200
    (+12mm topo / +168 base), carrinhos dentro dos trilhos, folgas da mesa
    - CAD/11-esqueleto-maquina_v1.step pronto p/ importar no Fusion 360
    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
    [11-esqueleto-maquina_v1.step]
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2026-10-03 Guia de montagem no Fusion (Docs/09) + STEPs de perfil 630 e fuso TR8
    - Fluxo definido com o Leandro: upload de cada STEP no Data Panel ->
    componente X-ref inserido um a um -> juntas rigidas + sliders ->
    simulacao de movimentos no Fusion
    - Divisao: scripts geram perfis/trilhos/fusos; Leandro traz STEPs de
    fabricante (carrinho MGN9C, mancal KP08/KFL08, castanha T8)
    - Docs/09: tabela de posicoes das pecas de fabricante em home, receita
    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
    [10-esqueleto-gantry_v1.step, fuso-tr8x8-400.step, idler-20t.step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]
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2026-10-03 Carrinho HIWIN MGN9H (step comercial do Leandro) + status na memoria
    - CAD/componentes/mgn9h-carrinho-hiwin.step (renomeado p/ convencao)
    - Memoria: Fase 1 do Fusion em andamento (Docs/10); pendente confirmar
    se os carrinhos fisicos sao MGN9C (assumido) ou MGN9H
    [mgn9h-carrinho-hiwin.step]
